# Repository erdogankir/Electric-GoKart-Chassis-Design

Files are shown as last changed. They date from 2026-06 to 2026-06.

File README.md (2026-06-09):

# Electric Go-Kart Chassis Design & Structural Optimization 🏎️⚡

This repository contains the conceptual design, mechanical engineering calculations, and Finite Element Analysis (FEA) of a handling-oriented electric go-kart chassis. 

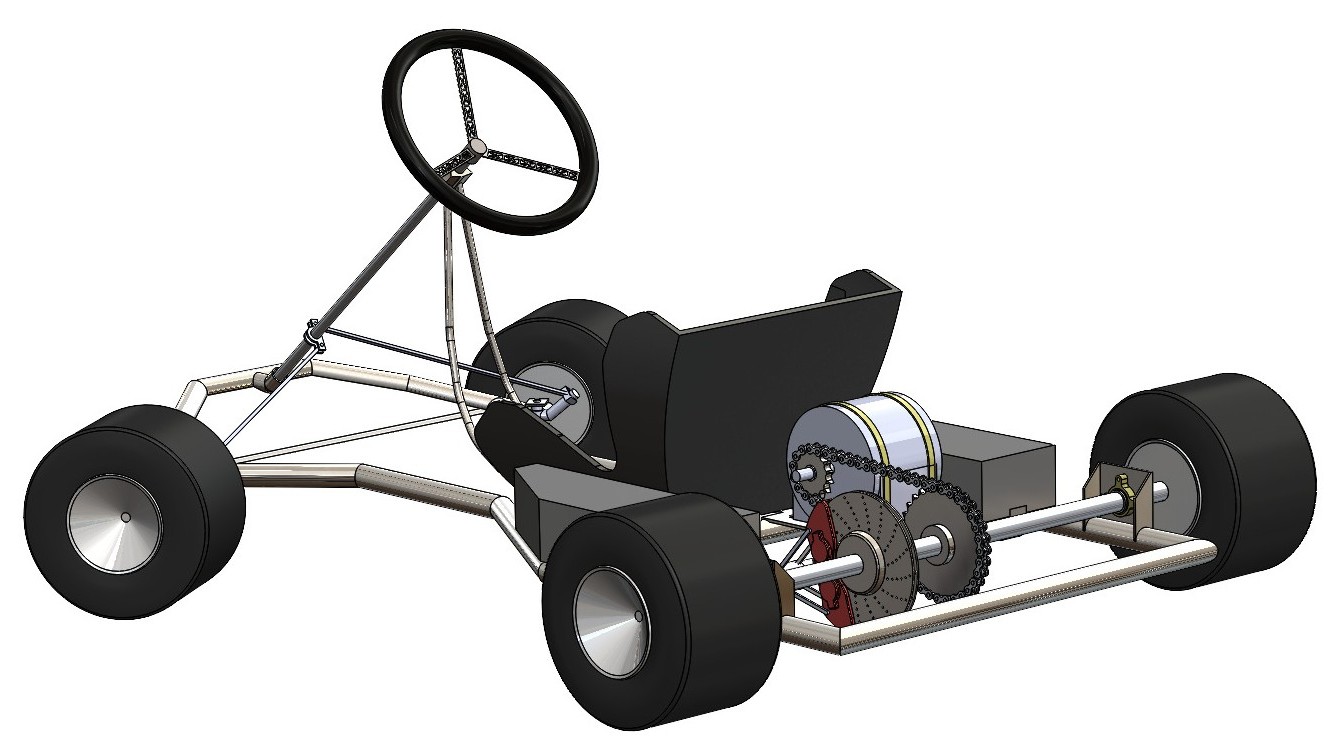
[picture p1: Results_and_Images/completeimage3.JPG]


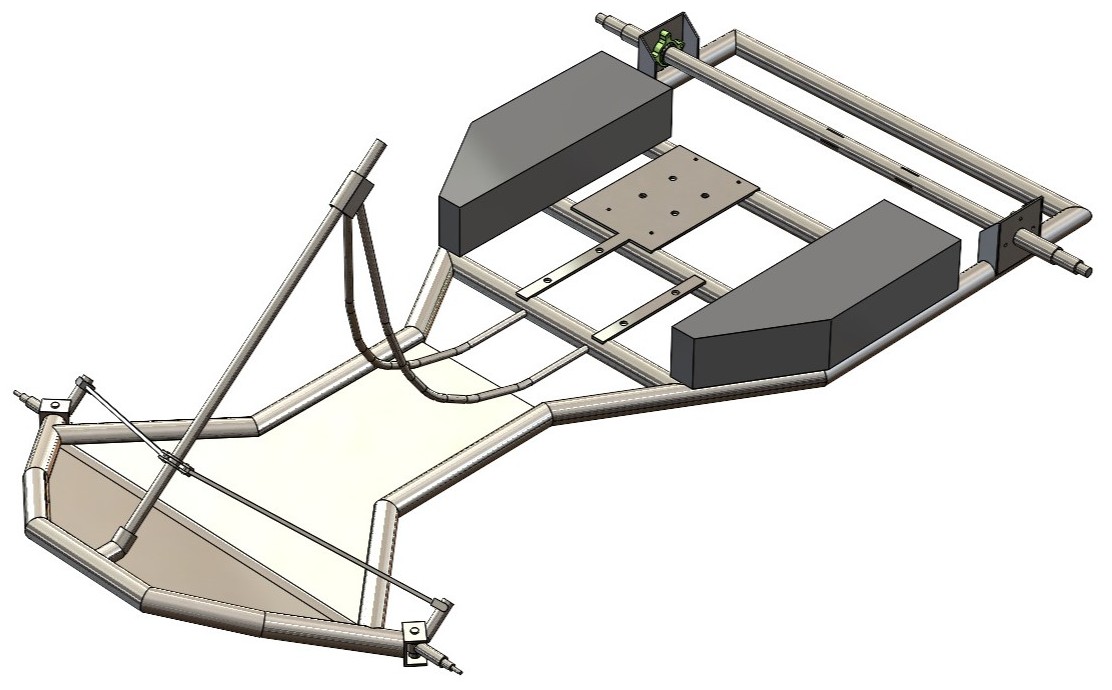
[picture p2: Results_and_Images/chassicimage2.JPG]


## 🎯 Project Overview
Unlike standard automobiles, go-karts lack a suspension system. This requires the chassis itself to act as the suspension. This project focuses on optimizing the torsional rigidity of the chassis to successfully achieve the **"jacking effect"** (lifting the inner rear wheel during cornering) to prevent understeer, effectively compensating for the added weight of an EV battery pack.

## ⚙️ Technical Specifications
* **Chassis Material:** S355 Structural Steel Tubing (32x2mm for main rails, 25x2mm for supports)
* **Powertrain:** 1.7 kW 48V Brushless DC (BLDC) Motor
* **Energy Storage:** 14S10P Li-Ion Battery Pack (18650 NMC cells, ~1.5 kWh) managed by a 60A BMS
* **Top Speed:** ~60 km/h (Optimized via 3.69 gear ratio)
* **Wheelbase / Track Width:** 1160 mm / 1400 mm

## 🔬 Engineering Methodology & Analysis
All design and simulation phases were executed using **SolidWorks 2024**. The engineering workflow includes:

1. **Vehicle Dynamics:** Quasi-Static Load Transfer calculations to determine cornering forces and theoretical load shifts.
2. **Global FEA (Beam Elements):** Initial displacement and rigidity tests under dynamic cornering loads (up to 550N lateral shock).
3. **Sub-Modeling (Solid Elements):** High-stress regions, particularly the steering knuckle connections (stub axles), were isolated and detailed using sub-modeling techniques. 
   * *Result:* Max Von Mises stress of **283 MPa** (Safely below the 355 MPa yield limit of S355 steel).
4. **Fatigue Analysis:** The 25mm rear axle was verified for infinite life under dynamic loads using the **Soderberg Criterion**.
5. **Stability:** Buckling analysis confirmed a critical load factor of 1.6.

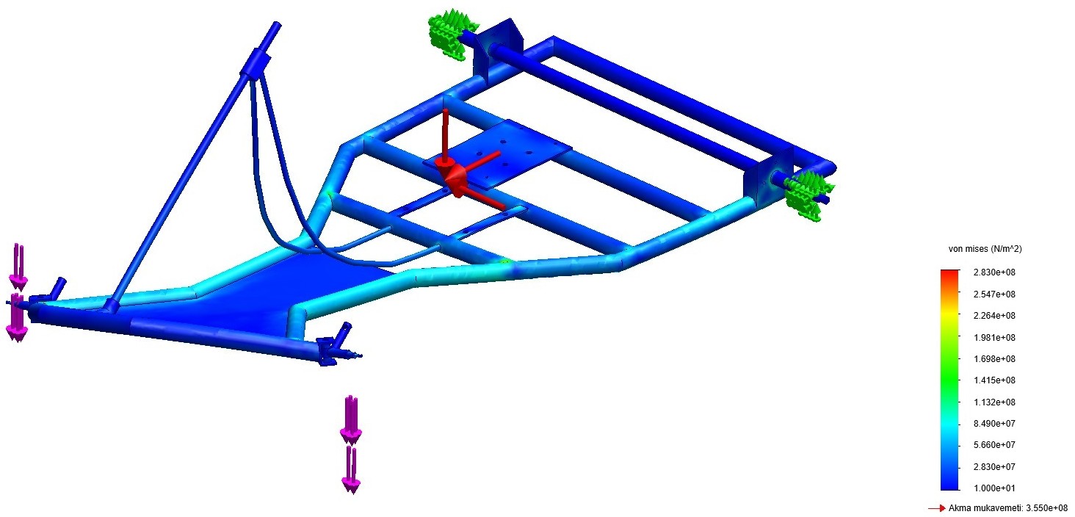
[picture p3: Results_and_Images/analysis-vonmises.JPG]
FEA Stress Distribution


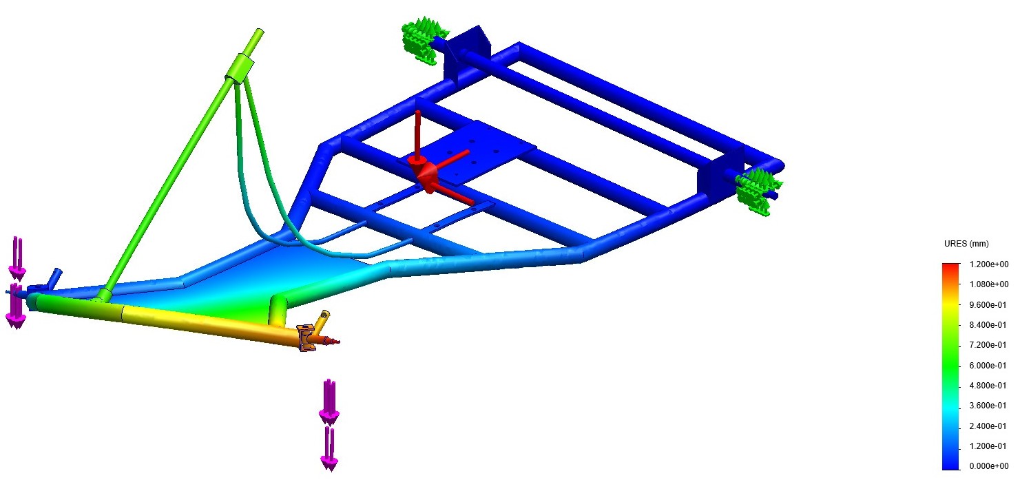
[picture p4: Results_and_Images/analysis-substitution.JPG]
FEA Substitution


## 📂 Repository Structure
* `/CAD_Models`: Contains SolidWorks native parts/assemblies (.sldprt, .sldasm) and exported .STEP files for universal access.
* `/Results_and_Images`: High-resolution CAD renders and FEA stress distribution contour plots.
* `/Documentations`: The comprehensive engineering design report (in Turkish) detailing all mathematical models, material selection, and cost analysis.

---
*Designed by Erdoğan Kır as a senior Mechatronics Engineering design project.*

NON-COMMERCIAL USE ONLY

---
# Elektrikli Go-Kart Şasi Tasarımı ve Yapısal Optimizasyonu 🏎️⚡

Bu depo, yol tutuş odaklı bir elektrikli go-kart şasisinin kavramsal tasarımını, makine mühendisliği hesaplamalarını ve Sonlu Elemanlar Analizi'ni (FEA) içermektedir.

Chassis Assembly

Chassis Assembly

## 🎯 Proje Özeti
Standart otomobillerden farklı olarak, go-kartlar bir süspansiyon sistemine sahip değildir. Bu durum, şasinin kendisinin bir süspansiyon elemanı gibi davranmasını zorunlu kılar. Bu proje, elektrikli araç batarya paketinin ek ağırlığını telafi ederek önden kaymayı (understeer) önlemek ve viraj dönüşlerinde iç arka tekerleği kaldırmak olan **"jacking effect"** (kaldırma etkisi) mekanizmasını başarıyla sağlamak için şasinin burulma rijitliğini optimize etmeye odaklanmaktadır.

## ⚙️ Teknik Özellikler
* Şasi Malzemesi:** S355 Yapı Çeliği Boru (Ana kollar için 32x2mm, destekler için 25x2mm) 
* **Güç Aktarma Sistemi:** 1.7 kW 48V Fırçasız DC (BLDC) Motor 
* Enerji Depolama:** 60A BMS ile yönetilen 14S10P Li-İyon Batarya Paketi (18650 NMC hücreler, ~1.5 kWh) 
* **Maksimum Hız:** ~60 km/s (3.69 dişli oranı ile optimize edilmiştir) 
* **Aks Aralığı / İz Genişliği:** 1160 mm / 1400 mm 

## 🔬 Mühendislik Metodolojisi ve Analiz
Tüm tasarım ve simülasyon aşamaları **SolidWorks 2024** kullanılarak gerçekleştirilmiştir. Mühendislik iş akışı şunları içerir:

1. **Araç Dinamiği:** Viraj kuvvetlerini ve teorik yük transferlerini belirlemek için Yarı-Statik Yük Transferi hesaplamaları.
2. **Global FEA (Kiriş Elemanlar):** Dinamik viraj yükleri altında (550N'a kadar yanal şok) ilk yer değiştirme ve rijitlik testleri.
3. **Alt Modelleme (Katı Elemanlar):** Özellikle direksiyon mafsal bağlantıları (stub axles) gibi yüksek gerilme bölgeleri izole edilmiş ve alt modelleme teknikleri kullanılarak detaylandırılmıştır.
   * *Sonuç:* Maksimum Von Mises gerilmesi **283 MPa** (S355 çeliğinin 355 MPa akma sınırının güvenli bir şekilde altındadır).
4. **Yorulma Analizi:** 25mm arka aks milinin dinamik yükler altındaki sonsuz ömrü **Soderberg Kriteri** kullanılarak doğrulanmıştır.
5. **Stabilite:** Burkulma analizi (buckling) 1.6'lık kritik yük faktörünü doğrulamıştır.

FEA Stress Distribution

FEA Substitution

## 📂 Depo Yapısı
* `/CAD_Models`: SolidWorks yerel parça/montaj dosyalarını (.sldprt, .sldasm) ve evrensel erişim için dışa aktarılmış .STEP dosyalarını içerir.
* `/Results_and_Images`: Yüksek çözünürlüklü CAD render'larını ve FEA gerilme dağılımı haritalarını içerir.
* `/Documentations`: Tüm matematiksel modelleri, malzeme seçimini ve maliyet analizini detaylandıran kapsamlı mühendislik tasarım raporu.

---
*Mekatronik Mühendisliği tasarım projesi olarak Erdoğan Kır tarafından tasarlanmıştır.* 

SADECE TİCARİ OLMAYAN KULLANIM İÇİNDİR

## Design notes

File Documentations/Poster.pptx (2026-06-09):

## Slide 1

YOL TUTUŞ ODAKLI ELEKTRİKLİ GO-KART
TASARIMI VE YAPISAL OPTİMİZASYONU
(Mekatronik Mühendisliği Tasarımı)

Erdoğan KIR Doç. Dr. Gökhan ATALI

32

Yapılan çalışma ve projede herhangi bir fon desteği alınmamıştır.

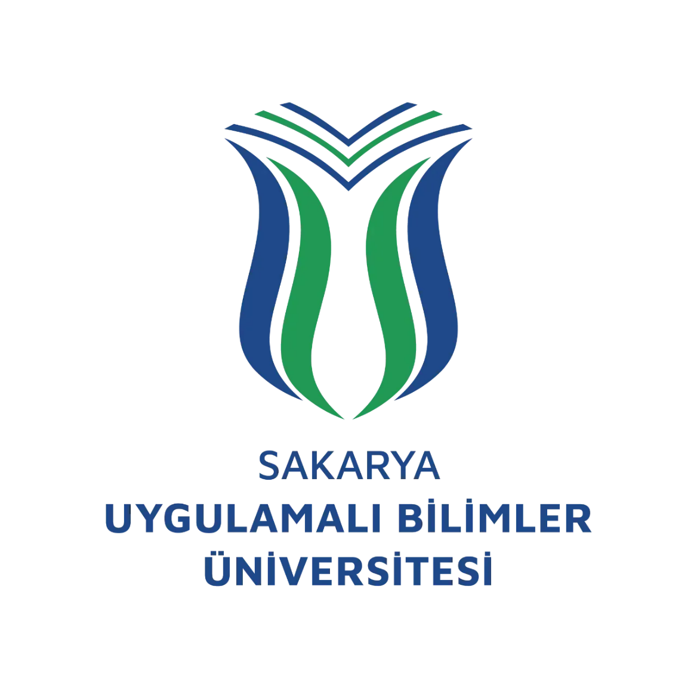
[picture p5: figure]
grafik, grafik tasarım, logo, simge, sembol içeren bir resim

MEKATRONİK
MÜHENDİSLİĞİ
PROJE SERGİSİ
2025-2026 Güz

3 2

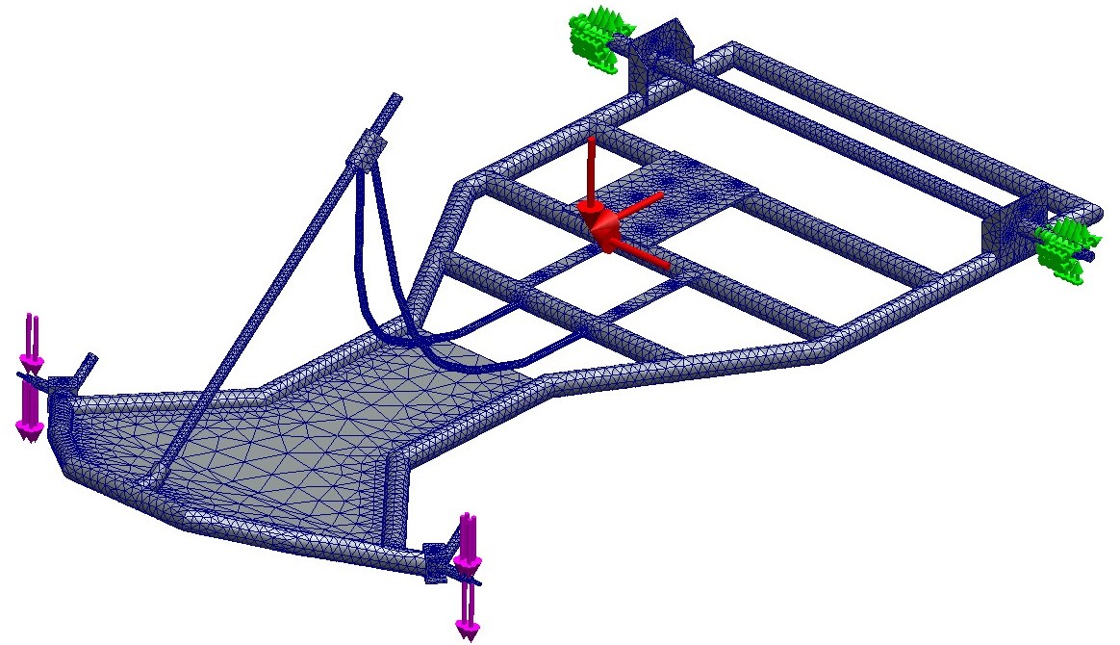
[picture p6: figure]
taslak, çizim, oyun alanı, çocuk bahçesi, çocukların yaptığı resimler içeren bir resim Yapay zeka tarafından oluşturulmuş içerik yanlış olabilir.

GİRİŞ

taslak, çizim, tasarım içeren bir resim Yapay zeka tarafından oluşturulmuş içerik yanlış olabilir.

SONUÇ & TARTIŞMA

32

Otomotiv endüstrisindeki radikal elektrifikasyon dönüşümü, motor sporlarının giriş seviyesi ve en saf hali olarak kabul edilen karting disiplinini de yeniden şekillendirmektedir. Özellikle kapalı alan (indoor) pistlerinde egzoz emisyonlarının yarattığı sağlık riskleri ve havalandırma maliyetleri, elektrikli tahrik sistemlerine olan talebi artırmıştır. Ayrıca, Fırçasız DC (BLDC) motorların içten yanmalı motorlara kıyasla sıfır devirden itibaren sunduğu maksimum tork avantajı, teorik olarak viraj çıkışlarında üstün bir ivmelenme performansı vadetmektedir. Ancak geleneksel go-kart araçlarının süspansiyonsuz yapısı, yol tutuş karakteristiğini doğrudan şasinin burulma rijitliğine (torsional rigidity) ve esnekliğine bağımlı kılmaktadır.
Bu çalışmadaki temel mühendislik problemi; elektrikli araç mimarisinin kaçınılmaz bir sonucu olan ağır batarya paketlerinin şasiye entegrasyonudur. Bu ek ağırlık, şasinin doğal frekansını ve esneklik merkezini değiştirerek, viraj performansı için hayati önem taşıyan "Jacking Effect" (viraj içi arka tekerleğin yerden kesilerek diferansiyel etkisi yaratılması) mekanizmasını bozma riski taşımaktadır. Şasinin gereğinden fazla rijit olması durumunda araç virajı dönemeyerek önden kayma (understeer) eğilimi gösterirken; aşırı esnek olması durumunda ise enerji sönümlenmesi nedeniyle direksiyon tepkileri gecikmektedir.
Bu bağlamda proje, literatürde kabul görmüş Gillespie (1992) araç dinamiği teorisi ve Mihalić ve ark. (2023) tarafından geliştirilen elektrikli şasi konsepti referans alınarak kurgulanmıştır. Çalışmanın nihai hedefi; S355 yapı çeliği ve yerel üretim imkanları (boru büküm, kaynaklı birleştirme) kullanılarak, batarya ağırlık dağılımının optimize edildiği, viraj içi frenleme ve dinamik yük senaryoları altında yapısal bütünlüğünü koruyan, maliyet etkin ve performanslı bir elektrikli go-kart platformu tasarlamaktır.

32

Yapısal Bütünlük ve Sonlu Elemanlar Analizi (FEA):
SolidWorks Simulation ortamında, viraj dışı tekerlek için belirlenen 550 N kritik tasarım yükü altında gerçekleştirilen statik analizlerde, şasi genelindeki maksimum yer değiştirme (deformasyon) şasi merkezinde yalnızca 1.2 mm olarak tespit edilmiştir. Bu düşük deformasyon değeri, şasinin "jacking effect" için gerekli rijitliğe sahip olduğunu kanıtlamaktadır. Von Mises gerilme analizi sonuçlarına göre; şasi üzerindeki maksimum gerilme, en zorlu yükleme senaryosunda dahi 283 MPa seviyesinde kalmıştır. Kullanılan S355 çeliğinin akma mukavemeti 355 MPa olduğu göz önüne alındığında, tasarımın plastik deformasyona uğramadan elastik sınırlar içerisinde güvenli bir şekilde çalıştığı doğrulanmıştır. Ayrıca, ince cidarlı borularda kritik bir risk olan burkulma (buckling) analizi sonucunda yük faktörü 1.6 olarak bulunmuş, bu da yapının mevcut yüklerin 1.6 katına kadar stabil kalabileceğini göstermiştir.

Kritik Bölge Doğrulaması ve Yorulma Ömrü:
Global analizde gerilme yığılmalarının yoğunlaştığı tespit edilen direksiyon mafsal bağlantıları (stub axle), "Alt Modelleme" (Sub-modeling) tekniği ile detaylandırılmıştır. Bu hassas analiz sonucunda, en kritik bölgedeki güvenlik katsayısının (FOS) 1.25 olduğu, şasi genelinde ise bu değerin 1.6 ile 4.0 arasında değiştiği görülmüştür . Yarış araçlarında ağırlık optimizasyonu için kabul edilebilir alt sınırın 1.25-1.5 olduğu düşünüldüğünde, tasarımın hem hafiflik hem de mukavemet açısından optimum noktada olduğu değerlendirilmiştir. Güç aktarım sisteminde ise, arka aks mili için uygulanan Soderberg Kriteri analizi, milin dinamik yükler altında sonsuz ömre sahip olacağını teorik olarak doğrulamıştır.

Maliyet Etkinliği ve Performans Kestirimi:
Tasarlanan elektrikli go-kart platformunun prototip üretim maliyeti, piyasa koşullarına göre (motor, batarya, şasi malzemeleri ve işçilik dahil) yaklaşık 97.420 TL olarak hesaplanmıştır. Bu maliyet, ithal edilen elektrikli yarış şasilerine kıyasla yerli üretimin ekonomik avantajını ortaya koymaktadır. Enerji yönetim simülasyonlarında, 1.7 kW motor ve 1512 Wh batarya paketi kombinasyonunun, aracı teorik olarak 60 km/s maksimum hıza ulaştırabileceği ve tam performanslı kullanımda 20 dakikalık yarış seansını termal limitlere takılmadan tamamlayabileceği öngörülmüştür.

taşımak, nakletmek, tekerlek, araba lastiği, Araba parçası içeren bir resim Yapay zeka tarafından oluşturulmuş içerik yanlış olabilir.

INTRODUCTIONasd

oyun alanı, çocuk bahçesi, ekran görüntüsü içeren bir resim Yapay zeka tarafından oluşturulmuş içerik yanlış olabilir.
oyun alanı, çocuk bahçesi, ekran görüntüsü, diyagram içeren bir resim Yapay zeka tarafından oluşturulmuş içerik yanlış olabilir.
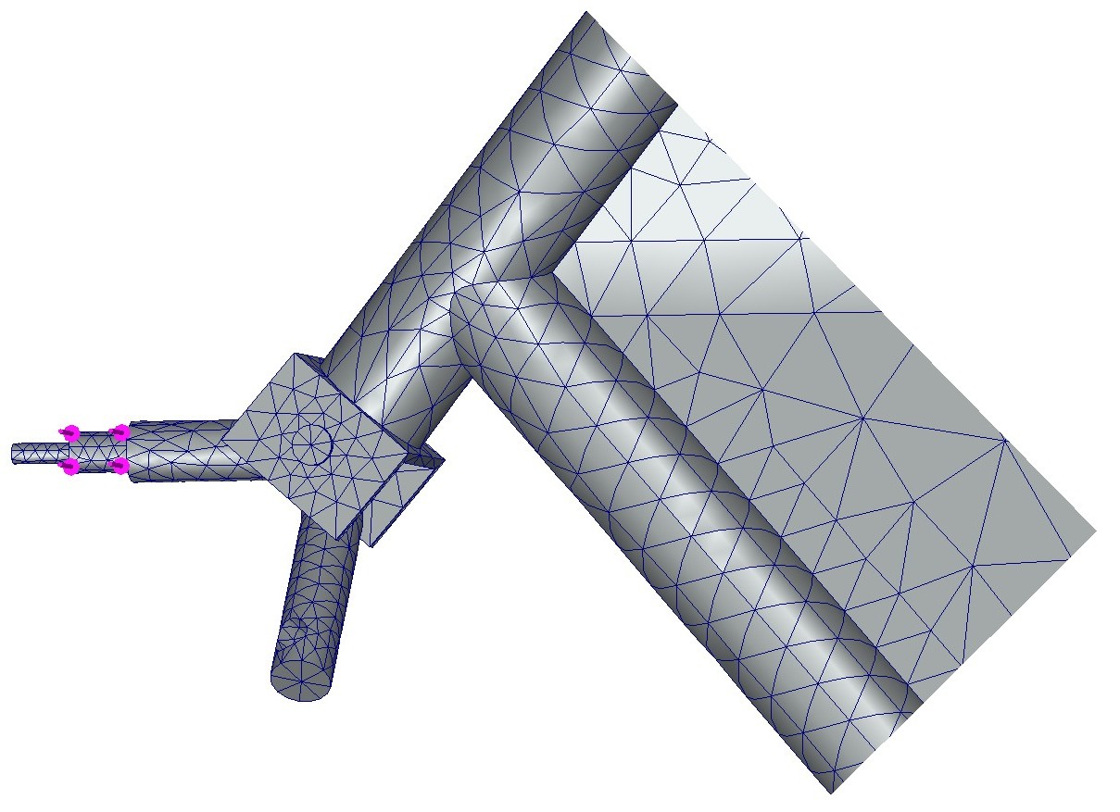
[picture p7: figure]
taslak, çizim içeren bir resim Yapay zeka tarafından oluşturulmuş içerik yanlış olabilir.
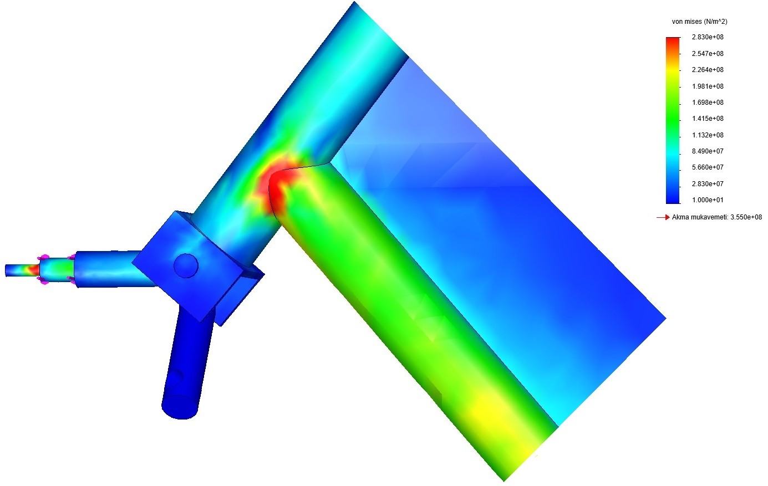
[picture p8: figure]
ekran görüntüsü, renklilik, grafik tasarım içeren bir resim Yapay zeka tarafından oluşturulmuş içerik yanlış olabilir.

32

Konsept Tasarım ve Malzeme Karakterizasyonu:
Bu çalışmada, sıfırdan şasi geometrisi oluşturmanın risklerini minimize etmek amacıyla literatür tabanlı "Tasarım Yoluyla Araştırma" (Research Through Design) metodolojisi benimsenmiştir. Şasi geometrisi, CIK-FIA tarafından belirlenen uluslararası standartlar (1040 mm aks aralığı ve 1400 mm iz genişliği) referans alınarak oluşturulmuş, ancak elektrikli tahrik sisteminin gereksinimleri doğrultusunda "side-pod" bölgeleri batarya taşıyıcı olarak yeniden yapılandırılmıştır. Malzeme seçiminde; havacılık çeliklerinin (AISI 4130) yüksek maliyeti ve düşük karbonlu çeliklerin (AISI 1020) yetersiz mukavemeti göz önüne alınarak optimizasyon yapılmış ve S355J2H dikişsiz çelik boru tercih edilmiştir . Seçilen malzemenin 355 MPa akma mukavemetine, 470-630 MPa çekme mukavemetine ve 7850 kg/m³ yoğunluğa sahip olması, şasi rijitliği ile ağırlık dengesinin korunmasını sağlamıştır . Şasi iskeletinde, yüksek burulma direnci gerektiren ana taşıyıcı hatlarda 32mm×2mm kesitli profiller kullanılırken; esneklik gerektiren ara bağlantı ve destek elemanlarında Ø25mm×2mm profiller kullanılarak ağırlık optimizasyonu sağlanmıştır.

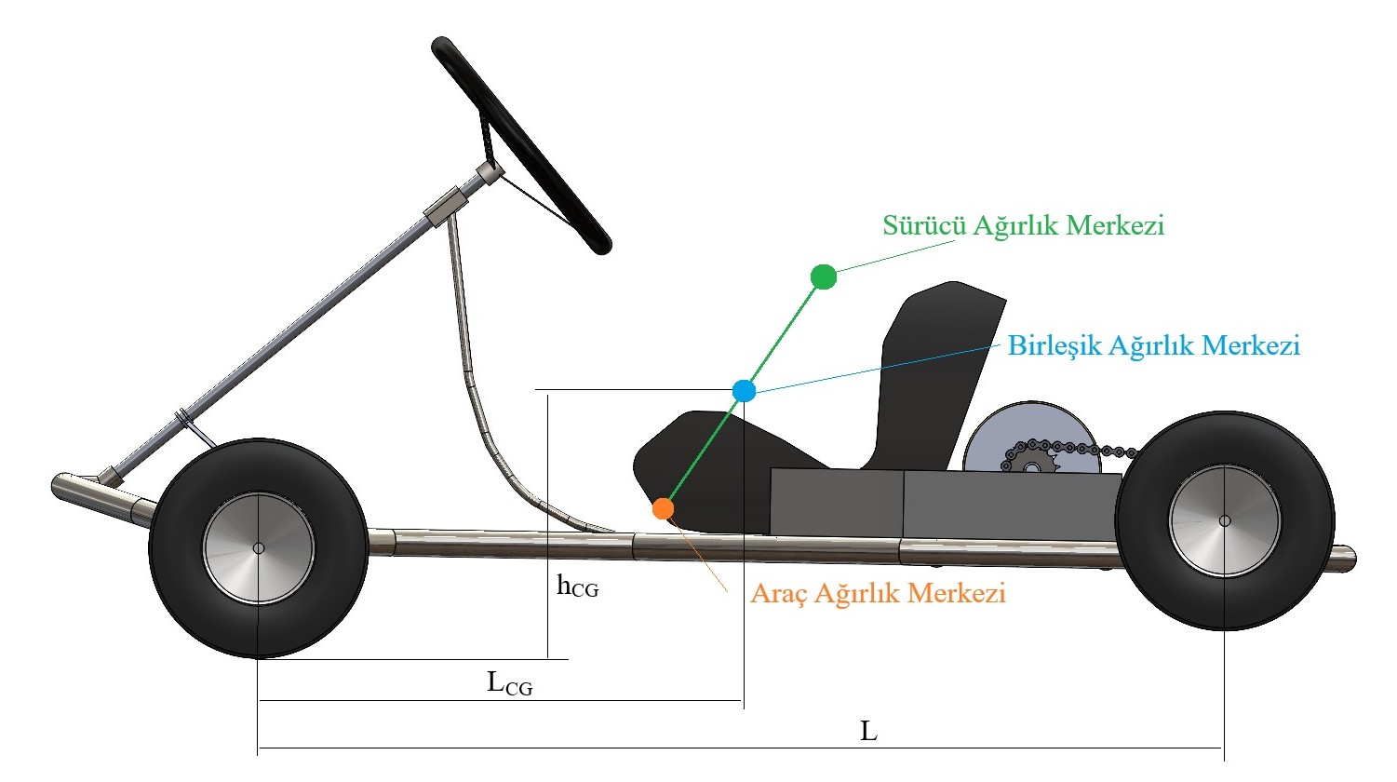
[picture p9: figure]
araba lastiği, tekerlek, Araba parçası, taşıt, araç içeren bir resim Yapay zeka tarafından oluşturulmuş içerik yanlış olabilir.

Yapısal Analiz (FEA) ve Güç Aktarım Entegrasyonu:
Aracın tahrik sistemi, toplam direnç kuvvetleri olan yuvarlanma ve aerodinamik dirençlerin (toplam 99.6 N) 16.6 m/s hızda yenilmesi prensibine göre boyutlandırılmıştır. Bu gereksinimi karşılamak üzere %90 sistem verimliliğine sahip 1.7 kW 48V Fırçasız DC (BLDC) motor sisteme entegre edilmiştir. Tork iletiminde zincir-dişli mekanizması kullanılmış; motor devri ve tekerlek devri oranlanarak 3.69:1 (13T Motor / 48T Aks) redüksiyon oranı belirlenmiştir. Enerji depolama ünitesi olarak, 20 dakikalık yarış süresi boyunca termal stabiliteyi koruyacak ve 1512 Wh enerji kapasitesi sunacak 14S10P konfigürasyonunda Li-Ion batarya paketi tasarlanmıştır. Batarya güvenliği, hücre voltajlarını 4.2V seviyesinde dengeleyen ve 60A üzeri akım çekiminde devreyi kesen Deligreen 14S BMS modülü ile sağlanmıştır. Ayrıca arka aks mili tasarımında Soderberg Yorulma Kriteri uygulanarak, dinamik eğilme ve burulma momentleri altında mil çapının 25 mm olması gerektiği doğrulanmıştır.

MATERYAL & YÖNTEM

Araç Dinamiği ve Yük Simülasyonu:
Aracın viraj alma performansı, Gillespie (1992) tarafından literatüre kazandırılan "Yarı-Statik Yük Transferi" (Quasi-Static Load Transfer) yaklaşımı ile modellenmiştir. Simülasyon senaryosu olarak; 16 metre viraj yarıçapında 10 m/s hızla seyreden ve 6.25 m/s² yanal ivmeye maruz kalan toplam 130 kg kütleli (sürücü dahil) bir araç modellenmiştir. Bu senaryoda ağırlık merkezi yüksekliğinin şasi stabilitesine etkisi analiz edilerek, viraj dışı tekerleklere etkiyen dinamik yükler teorik olarak hesaplanmıştır. Sonlu Elemanlar Analizi (FEA) süreçlerinde kullanılacak sınır şartları (boundary conditions) belirlenirken, sadece statik yükler değil, pist koşullarındaki olası darbeler de hesaba katılmıştır. Bu doğrultuda, viraj dışı arka tekerlek için teorik yükün üzerine dinamik şok faktörü eklenerek 550 N değerinde bir tasarım yükü tanımlanmış; viraj içi tekerlek yükü ise "jacking effect" kabiliyetini doğrulamak adına 100 N seviyesine düşürülmüştür. Analizlerde kaynaklı birleşimler "bonded" (yapışık) kabul edilmiş ve çözüm ağı (mesh) oluşturulurken kritik bölgelerde eleman boyutu 2 mm'ye kadar düşürülmüştür.

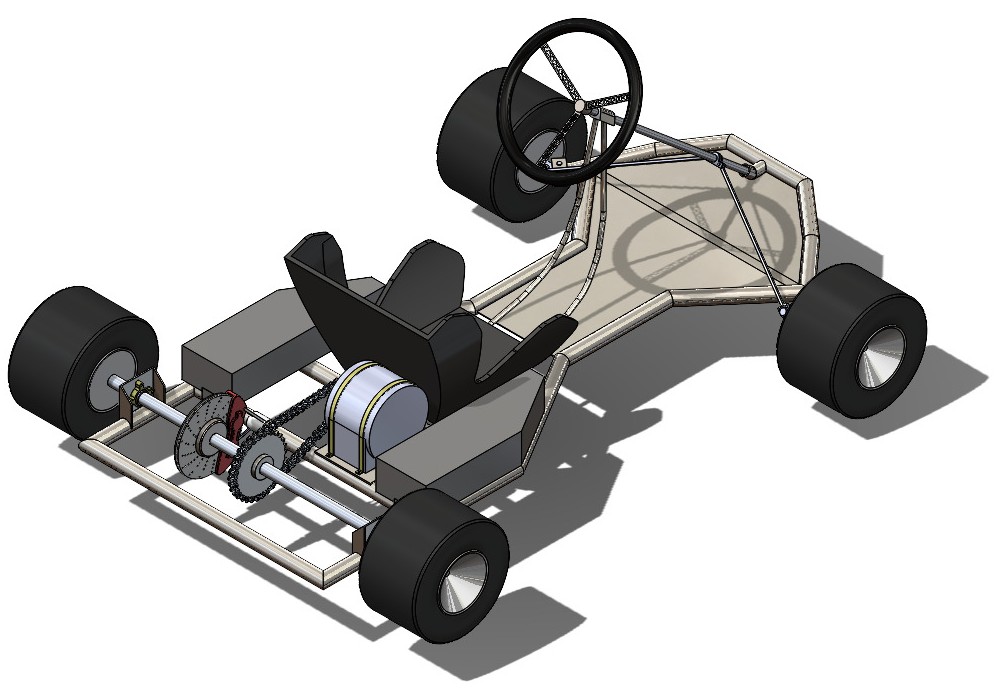
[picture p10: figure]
tekerlek, araba lastiği, taşımak, nakletmek, Araba parçası içeren bir resim Yapay zeka tarafından oluşturulmuş içerik yanlış olabilir.
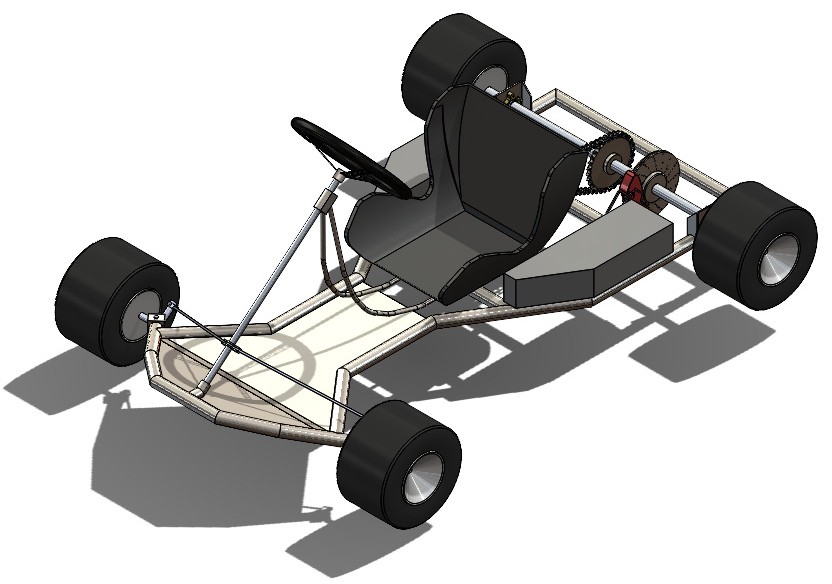
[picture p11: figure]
araba lastiği, tekerlek, taşımak, nakletmek, Araba parçası içeren bir resim Yapay zeka tarafından oluşturulmuş içerik yanlış olabilir.
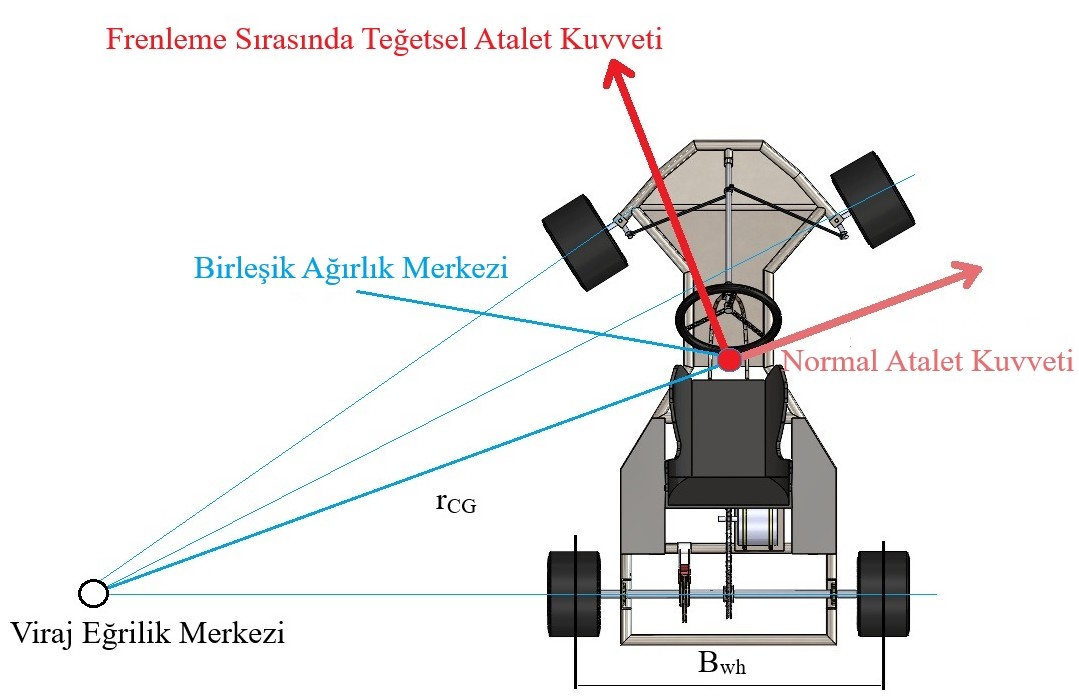
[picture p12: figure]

MATERIALS & METHODS

32

Bu proje, lisans seviyesinde bireysel bir tasarım çalışması olarak yürütüldüğünden, doğrulama süreçleri sanal prototipleme ve simülasyon ortamlarıyla sınırlı kalmıştır. Gelecek çalışmalarda, aracın fiziksel prototipinin üretilmesi ve şasi üzerine yerleştirilecek telemetri sensörleri (strain-gauge) ile esneklik davranışının gerçek pist koşullarında deneysel olarak doğrulanması önerilmektedir. Ayrıca, aracın güç/ağırlık oranını (power-to-weight ratio) daha da iyileştirmek adına; şasi malzemesi olarak mevcut S355 çeliği yerine daha hafif ve mukavemeti yüksek Krom-Molibden (AISI 4130) alaşımı kullanılabilir. Enerji depolama sisteminde ise, kullanılan 18650 Li-Ion hücreler yerine, gravimetrik enerji yoğunluğu daha yüksek olan Lityum-Polimer (Li-Po) batarya teknolojilerine geçiş yapılması, aracın dinamik performansını artıracaktır.

ÖNERİLER

32

Budynas, R.G. & Nisbett, K.J. (2011). Shigley's Mechanical Engineering Design. McGraw-Hill.
Gillespie, T.D. (1992). Fundamentals of Vehicle Dynamics. SAE International
Mihalić, T., Hoster, J., Tudić, V. & Kralj, T. (2023). 'Concept Design and Development of an Electric Go-Kart Chassis', Applied Sciences.
Milliken, W.F. & Milliken, D.L. (1995). Race Car Vehicle Dynamics. SAE International.

REFERANSLAR

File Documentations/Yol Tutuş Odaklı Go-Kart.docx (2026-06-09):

T.C.

SAKARYA UYGULAMALI BİLİMLER ÜNİVERSİTESİ
TEKNOLOJİ FAKÜLTESİ

MEKATRONİK MÜHENDİSLİĞİ BÖLÜMÜ

YOL TUTUŞ ODAKLI ELEKTRİKLİ GO-KART TASARIMI VE YAPISAL OPTİMİZASYONU

Mekatronik Mühendisliği Tasarımı Raporu

G180918066 Erdoğan KIR

Danışmanı | : | Doç. Dr. Gökhan ATALI

Ocak 2026

T.C.

SAKARYA UYGULAMALI BİLİMLER ÜNİVERSİTESİ
TEKNOLOJİ FAKÜLTESİ

MEKATRONİK MÜHENDİSLİĞİ BÖLÜMÜ

YOL TUTUŞ ODAKLI ELEKTRİKLİ GO-KART TASARIMI VE YAPISAL OPTİMİZASYONU

Mekatronik Mühendisliği Tasarımı Raporu

G180918066 Erdoğan KIR

Danışmanı | : | Doç. Dr. Gökhan ATALI

Danışman | Jüri | Jüri
Doç. Dr. Gökhan ATALI | Dr. Öğr. Üyesi Ayşe Nur AY GÜL | Arş. Gör. Nur Yasin PEKER

BEYAN

Rapor içindeki tüm verilerin akademik kurallar çerçevesinde tarafımdan elde edildiğini, görsel ve yazılı tüm bilgi ve sonuçların akademik ve etik kurallara uygun şekilde sunulduğunu, kullanılan verilerde herhangi bir tahrifat yapılmadığını, başkalarının eserlerinden yararlanılması durumunda bilimsel normlara uygun olarak atıfta bulunulduğunu, raporda yer alan verilerin bu üniversite veya başka bir üniversitede herhangi bir çalışmada kullanılmadığını beyan ederim.

Erdoğan KIR

05.12.2025

TEŞEKKÜR

Lisans eğitimim boyunca benden maddi ve manevi desteklerini esirgemeyen, her türlü zorlukta yanımda duran ve bu günlere gelmemde en büyük pay sahibi olan kıymetli aileme minnettarım.

Ayrıca, tasarım metodolojisi ve analiz akışının kurgulanmasında, 'Concept Design and Development of an Electric Go-Kart Chassis' başlıklı çalışmalarıyla yol gösterici olan Mihalić ve arkadaşlarına, akademik literatüre katkılarından dolayı teşekkürlerimi sunarım.

İÇİNDEKİLER

SİMGELER VE KISALTMALAR LİSTESİ

A | : Amper
A | : Araç ön projeksiyon alanı
Ah | : Ampere-Hour
AISI | : American Iron and Steel Institute
a_a^b | : Alternatif normal gerilme
a_m^b | : Ortalama normal gerilme
a_k^b | : Eğilme için gerilme katsayısı
a_(-1)^d | : Tersinir dinamik mukavemeti
a^y | : Yanal ivme
a^T | : Teğetsel ivme
a_k^t | : Burulma için gerilme katsayısı
BLDC | : Brushless Direct Current Motor
BMS | : Battery Management System
CAD | : Computer Aided Design
C_d | : Sürüklenme katsayısı
CIK | : Commission Internationale de Karting
CNC | : Computer Numerical Control
COG | : Center of Gravity
d | : Mil çapı
δ_0 | : Dış tekerlek açısı
δ_i | : İç tekerler açısı
ΔF_z | : Yük transferi
E | : Elastite modülü
EV | : Electric Vehicle
F_N^11 | : Ön sol lastik zemin reaksiyon kuvveti
F_N^12 | : Ön sağ lastik zemin reaksiyon kuvveti
F_N^21 | : Arka sol lastik zemin reaksiyon kuvveti
F_N^22 | : Arka sağ lastik zemin reaksiyon kuvveti
F_(aero) | : Aerodinamik direnç kuvveti
F_(dis) | : Yük transfer payı
F_(roll) | : Yuvarlanma direnci kuvveti
f_(roll) | : Yuvarlanma direnç katsayısı
F_(total) | : Toplam direnç kuvveti
FEA | : Finite Element Analysis
F_(in)^T | : Teğetsel atalet kuvveti
FIA | : Fédération Internationale de l’Automobile
FOS | : Factor of Safety
Φ | : Çap (Genel)
g | : Yerçekimi ivmesi
h_(CG) | : Ağırlık merkezi yüksekliği
i | : İdeal oran
kg (ağırlık) | : Kilogram
kW | : KiloWatt
L | : Aks aralığı
L_(CG) | : Ağırlık merkezinden ön aksa olan mesafe
LFP | : Lithium Iron Phosphate
LTO | : Lityum Titanat
M_b | : Eğilme momenti
M_T | : Tork
MPa | : Megapascal
m (uzunluk) | : Metre
mAh | : Miliampere Hour
mm (uzunluk) | : Milimetre
m/s | : Metre/Saniye
m/ s^2 | : Metre/Saniyekare
m_(com) | : Toplam kütle
m_d | : Sürücü kütlesi
m_i | : i 'inci bileşenin kütlesi
m_v | : Araç kütlesi
N | : Newton
n | : Güvenlik katsayısı
NMC | : Nikel Manganez Kobalt
ω | : İz genişliği
P | : Gerekli güç
P | : Paralel Bağlantı
PMSM | : Permanent Magnet Synchronous Motor
r_(CG) | : Viraj Yarıçapı
R_(eng) | : Motor Devri
R_(tire) | : Tekerlek Devri
r_a^t | : Alternatif kayma gerilmesi
r_m^t | : Ortalama kayma gerilmesi
ρ | : Yoğunluk
RPM | : Rotate Per Minute
S | : Seri Bağlantı
s | : Saniye
σ_a^(eku) | : Eşdeğer alternatif (yorulma) gerilmesi
σ_m^(eku) | : Eşdeğer ortalama gerilme
σ_(max) | : Maksimum gerilme
σ_(uts) | : Çekme momenti
σ_y | : Akma mukavemeti
T | : Dişli Diş Sayısı
TIG | : Tungsten Inert Gas
V | : Volt
V_(nom) | : Nominal gerilim
v | : Hız
W | : Watt
Wh | : Watt Hour
x_i | : Bileşenin referans nokta mesafesi

ŞEKİLLER LİSTESİ

TABLOLAR LİSTESİ

ÖZET

Anahtar Kelimeler: Elektrikli Go-Kart, Yol Tutuş Dinamiği, Şasi Tasarımı, Sonlu Elemanlar Analizi, Batarya Yönetim Sistemi, Araç Mühendisliği, Soderberg Kriteri.

Bu çalışma, Sakarya Uygulamalı Bilimler Üniversitesi Mekatronik Mühendisliği Tasarımı dersi kapsamında, içten yanmalı motorların çevresel dezavantajlarını elimine eden ve elektrik motorlarının tork avantajlarını kullanarak viraj alma kabiliyeti (yol tutuş) sergileyen bir elektrikli go-kart şasi ve güç aktarım sisteminin kavramsal tasarımını, mühendislik hesaplamalarını ve yapısal analizlerini içermektedir. Projenin temel motivasyonu, süspansiyon sistemine sahip olmayan go-kart araçlarında, şasi esnekliğinin ve rijitliğinin yol tutuş üzerindeki doğrudan etkisini optimize etmektir. Çalışma kapsamında, literatürde kabul görmüş tasarım ve analiz metodolojileri takip edilmiş; bu metodoloji, S355 çelik boru kullanılarak tarafımdan özgün olarak çizilen şasi geometrisi üzerinde uygulanmıştır

Tasarım sürecinde, aracın viraj içi frenleme, ani ivmelenme ve yol pürüzlerinden kaynaklanan darbe yükleri gibi kritik sürüş senaryoları modellenmiştir. Bu modellerden elde edilen viraj kuvvetleri, aracın yanal ivme altındaki davranışını simüle eden Yarı-Statik Yük Transferi (Quasi-Static Load Transfer) yöntemi ile hesaplanmış ve SolidWorks Simulation modülü kullanılarak Sonlu Elemanlar Analizi (FEA) ortamına aktarılmıştır. Şasinin gerilme dağılımı (Von Mises), yer değiştirme ve burkulma (buckling) davranışları incelenmiştir. Özellikle direksiyon mafsal bağlantıları (stub axle) gibi yüksek stres bölgeleri, alt modelleme (sub-modeling) tekniği ile detaylandırılarak, boru et kalınlığı/çap oranlarının güvenlik katsayıları üzerindeki etkisi irdelenmiştir. Arka aks mili tasarımı için Soderberg yorulma kriteri kullanılarak dinamik yükler altında mil ömrü doğrulanmıştır.

Analiz sonuçları, seçilen geometrinin 1.25 ile 2 arasında değişen güvenlik katsayıları ile elastik sınırlar içerisinde kaldığını ve yol tutuş için gerekli burulma esnekliğini sağladığını göstermiştir. Güç aktarma sisteminde, 1.7 kW güce sahip 48V Fırçasız DC (BLDC) motor ve 14S10P konfigürasyonunda Lityum-İyon batarya paketi kullanılmıştır. Batarya yönetim sistemi (BMS) entegrasyonu ve hücre dengeleme stratejileri, yarış koşullarında 20 dakika maksimum performans ve termal stabilite sağlayacak şekilde teorize edilmiştir. Araç dinamiği hesaplamalarında, ağırlık merkezi (COG) değişiminin lastik yük dağılımına etkisi ve diferansiyelsiz arka aksın viraj dönme mekaniği (jacking effect) üzerindeki rolü detaylıca analiz edilmiştir. Elde edilen bulgular, bu platformun hem yapısal bütünlük hem de dinamik performans açısından uygulanabilir, maliyet etkin ve performanslı bir çözüm sunduğunu ortaya koymaktadır.

ABSTRACT

Keywords: Electric Go-Kart, Handling Dynamics, Chassis Design, Finite Element Analysis, Battery Management System, Automotive Engineering, Soderberg Criterion.

This study presents the conceptual design, engineering calculations, and structural analyses of an electric go-kart chassis and powertrain system, developed within the scope of the Mechatronics Engineering Design course at Sakarya University of Applied Sciences. The study aims to eliminate the environmental disadvantages of internal combustion engines while utilizing the torque advantages of electric motors to exhibit superior cornering capability (handling). The project’s core motivation focuses on optimizing the direct impact of chassis flexibility and rigidity on handling in suspensionless go-kart vehicles. Within the scope of this study, design and analysis methodologies accepted in the literature were followed; this methodology was applied to a unique chassis geometry designed by the author using S355 steel tubing.

In the design process, critical driving scenarios such as braking during cornering, sudden acceleration, and impact loads resulting from road irregularities were modeled. Cornering forces obtained from these models were calculated using the Quasi-Static Load Transfer method to simulate the vehicle's behavior under lateral acceleration and were transferred to the Finite Element Analysis (FEA) environment using the SolidWorks Simulation module. The chassis was examined for Von Mises stress distribution, displacement, and buckling behaviors. High-stress regions, particularly the steering knuckle connections (stub axles), were detailed using the sub-modeling technique to investigate the effect of wall thickness-to-diameter ratios on safety factors. For the rear axle shaft design, the shaft life under dynamic loads was verified using the Soderberg fatigue criterion.

The analysis results demonstrated that the selected geometry remains within elastic limits with safety factors ranging between 1.25 and 2, providing the necessary torsional flexibility for optimal handling. The powertrain system utilizes a 1.7 kW 48V Brushless DC (BLDC) motor and a Lithium-Ion battery pack in a 14S10P configuration. Battery Management System (BMS) integration and cell balancing strategies were theorized to ensure thermal stability and maximum performance for 20 minutes under racing conditions. In vehicle dynamics calculations, the effect of Center of Gravity (COG) shifts on tire load distribution and the role of the differential-less rear axle on cornering mechanics (jacking effect) were analyzed in detail. The findings reveal that this platform offers a feasible, cost-effective, and high-performance solution in terms of both structural integrity and dynamic performance.

BÖLÜM 1. GİRİŞ

1.1. Çalışmanın Arka Planı ve Otomotiv Endüstrisindeki Dönüşüm

Otomotiv endüstrisi, son yüzyılın en köklü dönüşümlerinden birini yaşamakta ve fosil yakıtlı içten yanmalı motorlardan , sürdürülebilir ve yüksek verimli elektrikli tahrik sistemlerine (EV) geçiş yapmaktadır (Ehsani, Gao ve Emadi, 2010). Bu dönüşüm, yalnızca günlük ulaşım araçlarını değil, motor sporlarını da derinden etkilemektedir. Motor sporlarının giriş seviyesi ve en saf hali olarak kabul edilen "Karting", sürücülerin araç dinamiğini, yol tutuş limitlerini ve yarış çizgisi disiplinini öğrendikleri temel branştır. Geleneksel go-kartlar, basit mekanik yapıları, düşük ağırlık merkezleri ve süspansiyonsuz tasarımları ile bilinirler.

Özellikle kapalı alan (indoor) karting pistlerinde, egzoz gazlarının yarattığı havalandırma maliyetleri ve sağlık riskleri, elektrikli go-kartlara olan talebi artırmıştır. Elektrik motorlarının sıfır devirden itibaren maksimum tork üretebilme yeteneği, viraj çıkışlarında içten yanmalı motorlara kıyasla teorik olarak daha üstün bir ivmelenme performansı sunmaktadır. Ancak, elektrikli araçların en büyük handikabı olan batarya ağırlığı, hafiflik üzerine kurulu olan go-kart felsefesi ile çelişmektedir. Bu noktada, mühendislik disiplini devreye girmekte ve ağırlık dezavantajını, optimize edilmiş şasi geometrisi ve ağırlık dağılımı ile telafi ederek yol tutuş karakteristiğini koruma zorunluluğu doğmaktadır.

Bu proje akademik bir çerçevede endüstriyel standartlara yakın bir elektrikli go-kart platformu geliştirmek amacıyla kurgulanmıştır. Projenin arkasındaki temel motivasyon, yalnızca bir araç tasarlamak değil, aynı zamanda şasi esnekliğinin araç dinamiği üzerindeki etkisini matematiksel ve simülasyon tabanlı yöntemlerle kanıtlayarak başarılı ve teknik açıdan dolu bir mühendislik raporu ortaya koymaktır. Bu bağlamda, proje, literatürdeki başarılı tasarımların derinlemesine analizi ve bu tasarımların yerel imkanlar dahilinde optimize edilerek yeniden yorumlanması üzerine inşa edilmiştir.

1.2. Problem Tanımı: Yol Tutuş ve Elektrikli Tahrik Entegrasyonu

Go-kartlar, otomobillerden farklı olarak süspansiyon sistemine (yay, amortisör) sahip değildir. Bu durum, şasinin kendisinin bir süspansiyon elemanı gibi davranmasını zorunlu kılar. Aracın yol tutuşu, şasinin burulma rijitliği (torsional rigidity) ve esneklik karakteristiği ile doğrudan ilişkilidir. Viraj alma sırasında, şasi belirli bir miktarda esneyerek, diferansiyel bulunmayan arka aksın viraj içindeki tekerleğini yerden kesmeli veya yükünü minimize etmelidir. Buna jacking effect (kaldırma etkisi) denir. Eğer şasi çok rijit olursa, iç tekerlek kalkmaz ve araç virajı dönemeyerek önden kayar (understeer). Eğer şasi çok esnek olursa, enerji sönümlenir ve direksiyon tepkisi gecikir.

Elektrikli bir go-kartta, ağır batarya paketlerinin şasiye eklenmesi, şasinin doğal frekansını ve esneklik merkezini değiştirir. İçten yanmalı motorlu bir araca göre tasarlanmış standart bir şasiye elektrik motoru ve batarya takıldığında, aracın yol tutuş karakteristiği bozulur. Problem şudur: Ek batarya ağırlığına rağmen, virajlarda nötr veya hafif arkadan kayma (oversteer) eğilimli, yüksek yol tutuşa sahip ve mekanik olarak güvenli bir şasi geometrisi nasıl elde edilir?

1.3. Amaç ve Hedefler

Bu çalışmanın ana amacı, yol tutuş odaklı, elektrik tahrikli ve tek kişilik bir go-kart şasisi ve güç aktarım sistemi tasarlamaktır. Alt hedefler şunlardır:

1. Platform Seçimi ve Geliştirme: Sıfırdan şasi geometrisi yaratmanın getirdiği zaman ve bilgi birikimi kısıtlarını aşmak için, literatürde başarısı kanıtlanmış bir şasi geometrisinin referans alınarak, elektrikli bileşenlere uygun hale getirilmesi.
2. Mühendislik Hesaplamaları: Araç dinamiği, viraj kuvvetleri, ağırlık transferi, motor gücü ve batarya kapasitesi gibi parametrelerin teorik formüllerle hesaplanması.
3. Yapısal Analiz (FEA): Şasinin statik ve dinamik yükler (viraj, fren, darbe) altındaki davranışının SolidWorks Simulation ile analiz edilmesi ve güvenlik katsayılarının doğrulanması.
4. Enerji Yönetimi: Yarış koşulları için gerekli batarya kapasitesini ve BMS mimarisini belirlemek.

1.4. Projenin Kapsamı ve Sınırlılıkları

Bu rapor, aracın kavramsal tasarımını, detaylı mekanik analizlerini ve bileşen seçimlerini kapsamaktadır. Çalışma, fiziksel prototip üretiminden önceki nihai tasarım raporu niteliğindedir. Analizlerde şasi malzemesi olarak S355 çeliği kullanılmış, kaynaklı birleşimlerin ideal olduğu varsayılmıştır. Aerodinamik etkiler, aracın maksimum hızının (60 km/s) düşük olması nedeniyle basitleştirilmiş formüllerle hesaba katılmıştır.

BÖLÜM 2. LİTERATÜR ARAŞTIRMASI VE TEORİK ALTYAPI

2.1. Karting Disiplininin Mekanik Evrimi

Karting, 1956 yılında Art Ingels'in ilk aracı üretmesinden bu yana, basit mekanik yapılardan yüksek mühendislik ürünü araçlara evrilmiştir. Modern şasiler, CIK-FIA standartlarına göre krom-molibden veya karbon çeliklerinden üretilir. Şasinin esnekliği, lastiklerin yerle temasını optimize etmek için ayarlanabilir bir parametre olarak kullanılır. Elektrikli kartingde ise bu parametrelere batarya yerleşimi ve motor tork eğrisi yönetimi eklenmiştir.

2.2. Elektrikli Tahrik Sistemleri Literatürü

2.2.1. Fırçasız Doğru Akım (BLDC) Motor Karakteristikleri

Literatürde go-kart uygulamaları için en verimli motor tipinin BLDC veya PMSM olduğu belirtilmektedir. BLDC motorlar, fırçalı motorlara göre daha yüksek verim, daha yüksek güç yoğunluğu ve bakım gerektirmemesi nedeniyle tercih edilir. En kritik özelliği, geniş bir devir aralığında sabit tork sunabilmesidir, bu da vites kutusu ihtiyacını ortadan kaldırır.

2.2.2. Enerji Depolama: Li-Ion Hücre Kimyası ve Yönetimi

Enerji yoğunluğu (Wh/kg) açısından Lityum-İyon piller endüstri standardıdır (Miao ve ark., 2019). Go-kart tasarımında pil tercihi için üç ana başlık öne çıkar:

1. LFP ( LiFePO_4 ): Güvenli, uzun ömürlü (>2000 döngü), düşük enerji yoğunluğuna sahiptir.
2. NMC: Yüksek enerji yoğunluğuna sahiptir, otomotivde yaygındır.
3. LTO: Çok hızlı şarj edilebilme kapasitesi vw bunun getirisi olarak yüksek maliyetlidir.

Bu projede, performans/ağırlık gerekçesiyle NMC kimyasına sahip 18650 silindirik hücreler üzerine yoğunlaşılmıştır.

2.3. Araç Dinamiği Teorisi

2.3.1. Lastik-Yol Etkileşimi ve Sürtünme Çemberi

Bir aracın tüm kontrolü, lastiklerin yerle temas ettiği contact patch alanında gerçekleşir. Gillespie (1992) tarafından tanımlanan sürtünme çemberi teorisine göre, bir lastiğin üretebileceği maksimum yanal ve boylamasına kuvvetlerin bileşkesi, lastiğin sürtünme limitini aşamaz. Go-kartlarda süspansiyon olmadığı için, yük transferi doğrudan şasi esnekliği üzerinden lastiklere iletilir.

2.3.2. Ackermann Direksiyon Geometrisi ve Viraj Kinematiği

Düşük hızlarda tekerleklerin kaymadan dönmesi için Ackermann şartı (Denklem 3.1) sağlanmalıdır (Jazar, 2014).

cot(δ_0 )-cot(δ_i )=ω/L (3.1)

Burada δ_0 dış, δ_0 iç tekerlek açısı, ω iz genişliği ve L aks aralığıdır. Go-kartlarda bu geometri, viraj girişinde direksiyon çevrildiğinde ön tekerleklerin yükseklik farkı yaratarak şasiyi kurtarması ve iç arka tekerleği kaldırması için modifiye edilir.

2.3.3. Jacking Etkisi ve Yük Transferi Mekaniği

Diferansiyelsiz arka aks, virajda her iki tekerleği aynı hızda dönmeye zorlar. Dış tekerlek daha uzun yol alması gerektiğinden, iç tekerlek kaymak (scrubbing) zorundadır. Bu, aracı düz gitmeye zorlar (understeer). "Jacking" etkisi, şasinin esneyerek viraj içindeki arka tekerleğin üzerindeki yükü sıfıra indirmesi (veya havaya kaldırması) prensibidir. Bu sayede araç üç tekerlek üzerinde dönerek diferansiyel etkisi yaratır. Yük transferi ( ΔF_z ) şu şekilde (Denklem 3.2) ifade edilir:

ΔF_z =(m.a_y .h_(CG))/ω (3.2)

Ağırlık merkezi yüksekliğinin ( h_(CG) ) optimize edilmesi bu nedenle kritiktir.

2.4. Şasi Malzemeleri ve Metalurjik İnceleme

Şasi malzemesi seçiminde mukavemet, tokluk, kaynaklanabilirlik ve maliyet dengesi gözetilir. Literatürdeki çalışmalar incelendiğinde üç ana malzeme grubu öne çıkmaktadır:

- Krom-Molibden Çeliği (AISI 4130): Havacılık ve profesyonel yarış şasilerinde standarttır. Yüksek akma mukavemeti (460 MPa) ve mükemmel yorulma direnci sunar. Ancak kaynak sonrası ısıl işlem gerektirmesi ve yüksek maliyeti, öğrenci projeleri için erişilebilirliğini kısıtlar.
- Düşük Karbonlu Çelikler (AISI 1018 / 1020): Kolay işlenir, ucuzdur ancak mukavemeti düşüktür (300 MPa), bu da şasinin ağırlaşmasına neden olur.
- Yapı Çeliği (S355 / St52): Bu çalışmada tercih edilen malzemedir. Akma mukavemeti ( σ_y =355 MPa) ile AISI 4130'a yaklaşırken, maliyet ve kaynaklanabilirlik açısından karbon çeliklerinin avantajlarını sunar. Tokluğu yüksektir, darbe anında gevrek kırılma yerine plastik deformasyon gösterir.

BÖLÜM 3. MATERYAL VE YÖNTEM

3.1. Konsept Tasarım Yaklaşımı ve Geometri Seçimi

Sıfırdan şasi geometrisi yaratmanın riskleri göz önüne alınarak, Tasarım Yoluyla Araştırma (Research Through Design) metodolojisi izlenmiştir. CIK-FIA onaylı şasilerin geometrik parametreleri aks aralığı 1040mm ve iz genişliği 1400mm referans alınmış, bu geometri elektrik motoru ve batarya paketlerinin yerleşimine uygun olarak modifiye edilmiştir. Özellikle side pod bölgeleri batarya taşıyıcı olarak yeniden tasarlanmıştır.

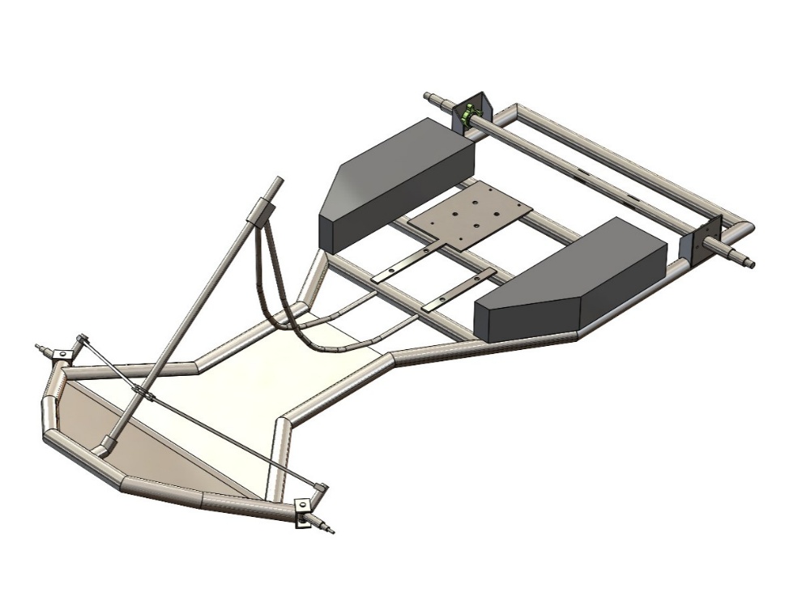
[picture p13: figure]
taslak, çizim, sandalye, tasarım içeren bir resim Yapay zeka tarafından oluşturulmuş içerik yanlış olabilir.

Şekil 3.1. SolidWorks ortamında tasarlanan şasi geometrisinin ön mafsallar, direksiyon mili ve batarya kutusu yerleşiminin izometrik görünümü.

3.2. Malzeme Seçimi ve Özelllikleri

Şasi ana taşıyıcı boruları için S355J2H dikişsiz çelik boru seçilmiştir. Malzeme özellikleri:

- Akma Mukavemeti ( σ_y ): 355 MPa
- Çekme Mukavemeti ( σ_(uts) ): 470-630 MPa
- Elastisite Modülü ( E ): 210 GPa
- Yoğunluk ( ρ ): 7850 kg/m³

Kullanılan boru kesitleri:

- Ana Şasi Kolları: Φ 32mm x 2mm (Dış Çap x Et Kalınlığı) Yüksek rijitlik gerektiren bölgeler.
- Ara Bağlantılar ve Destekler: Φ 25mm x 2mm Esneklik ve hafiflik gerektiren bölgeler.

3.3. Bilgisayar Destekli Tasarım (CAD) Süreci

Şasinin 3 boyutlu modellemesi SolidWorks 2024 yazılımında gerçekleştirilmiştir (Dassault Systèmes, 2023). Modelleme sürecinde Katı Modülleme (Solid Modelling) modülü kullanılarak, boru profillerin birleşim noktaları otomatik olarak düzenlenmiş ve kesim listeleri hazır hale getirilmiştir. Batarya kutuları, motor ve direksiyon bileşenleri ise montaj (assembly) ortamında şasiye entegre edilerek hacim ve ağırlık kontrolleri yapılmıştır.

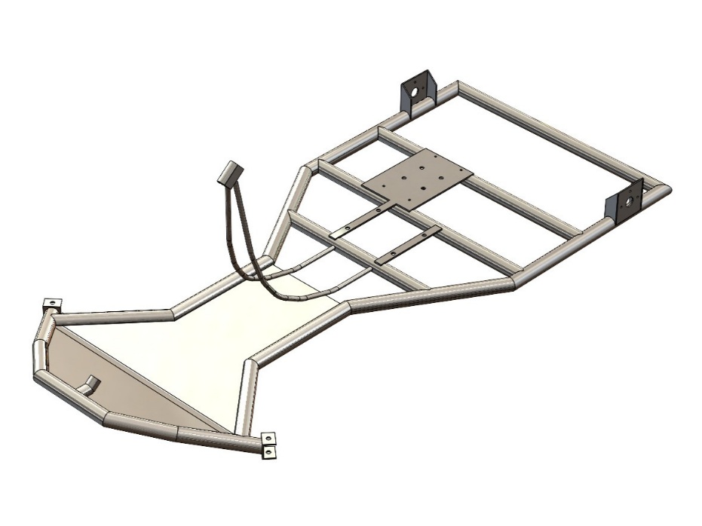
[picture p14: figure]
taslak, çizim, tasarım içeren bir resim Yapay zeka tarafından oluşturulmuş içerik yanlış olabilir.

Şekil 3.2. Katı modelleme modülü ile oluşturulan şasi iskelet yapısının ve bağlantı noktalarının genel görünümü.

3.4. Sonlu Elemanlar Analizi (FEA) Metodolojisi

Yapısal analizler, SolidWorks Simulation eklentisi ile yapılmıştır. Analiz adımları:

1. Ön İşlem (Pre-processing): Malzeme ataması ve bağlantı koşullarının belirlenmesi. Kaynaklı birleşimler bonded (yapışık) olarak kabul edilmiştir.
2. Mesh (Ağ) Oluşturma: İki aşamalı bir yaklaşım izlenmiştir.

Kiriş (Beam) Mesh: Tüm şasi, hesaplama hızı için kiriş elemanlarla modellenmiştir. Bu, şasinin genel deplasmanını görmek için idealdir. Katı (Solid) Mesh: Kritik gerilme bölgeleri (direksiyon mafsalları) katı elemanlarla modellenmiş, eleman boyutu 2 mm'ye kadar düşürülmüştür.

3. Çözüm (Solution): Statik analiz ve burkulma (buckling) analizi çözücüleri kullanılmıştır.
4. Son İşlem (Post-processing): Von Mises gerilme dağılımları, güvenlik katsayısı (FOS) grafikleri ve deformasyonlar görselleştirilmiştir.

BÖLÜM 4. MÜHENDİSLİK HESAPLAMALARI

4.1. Sürücü ve Araç Kütle Merkezi (COG) Analizi

Yol tutuşun kutsal kasesi ağırlık merkezidir. Aracın toplam kütlesi ( m_v ) 50 kg (bataryalar dahil), sürücü kütlesi ( m_d ) 80 kg olarak alınmıştır. Toplam kütle ( m_(com) ) 130 kg'dir.

SolidWorks kütle özellikleri aracından alınan veriler ve teorik formüllerle (Denklem 4.1) hesaplanan değerler:

L_(CG) =(m_i x_i)/(m_i) (4.1)

- Ağırlık Merkezi Yüksekliği ( h_(CG) ): 0,35 m
- Ön Aksa Mesafe ( L_(CG) ): 0,65 m
- Aks Aralığı ( L ): 1,16 m

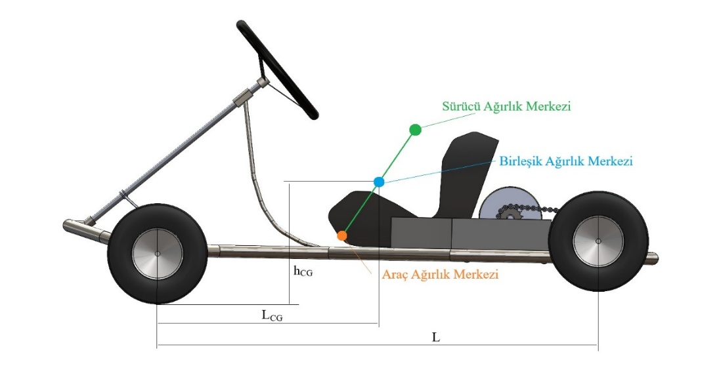
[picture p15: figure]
araba lastiği, tekerlek, Araba parçası, taşımak, nakletmek içeren bir resim Yapay zeka tarafından oluşturulmuş içerik yanlış olabilir.

Şekil 4.1. Sürücü ve araç bileşenlerinin ağırlık merkezlerinin (COG) dikey konumu ve aks mesafelerinin şematik gösterimi.

4.2. Yarı-Statik Yük Transferi Analizi (Quasi-Static Load Transfer)

4.2.1. Teorik Yük Transferi Hesabı

Aracın viraj alma performansı ve şasi üzerine binen yükler, Gillespie (1992) tarafından tanımlanan Yarı-Statik Yük Transferi yaklaşımı ile analiz edilmiştir. Varsayılan Senaryo:

- Viraj Yarıçapı ( r_(CG) ): 16 m
- Araç Hızı ( v ): 10 m/s
- Toplam Kütle ( m_(com) ): 130 kg
- Ağırlık Merkezi Yüksekliği ( h_(CG) ): 0.35 m
- İz Genişliği ( ω ): 1.4 m

İlk olarak araca etkileyen yanal ivme ( a_y ) ve merkezkaç kuvvetleri hesaplanmıştır (Denklem 4.2):

a_y =(v^2)/(r_(CG))=6,25 m/s^2 (4.2)

Toplam yanal yük transferi ( ΔF_z ), ağırlık merkezi yüksekliği ve iz genişliği oranına bağlı olarak şu şekilde bulunur (Denklem 4.3):

ΔF_z =(m_(com) .a^y .h_(CG))/ω=203,1 N (4.3)

Aracın 4 tekeri olduğu ve ağırlığın eşit dağıldığını varsaydığımız (basit yaklaşım) için (Denklem 4.4):

(1275,3)/4=318,8 N (4.4)

Yük transferi payı (Denklem 4.5):

(203,1)/2=101,55

F_(dis) =318+101,5=419,5 N (4.5)

Bu hesaba göre, viraj dışındaki tekerleğe binen teorik yük yaklaşık 420 N (318 + 101.5) seviyesindedir. Ancak statik hesaplamalar, yarış sırasındaki dinamik şokları kapsamamaktadır.

4.2.2. FEA Analizleri İçin Tasarım Yüklerinin (Boundary Conditions) Belirlenmesi

Şasinin sınırlarını test etmek amacıyla, teorik hesaplamaların üzerine Dinamik Yük Faktörü eklenerek analiz yükleri artırılmıştır. Tablo 4.1'de, Sonlu Elemanlar Analizi'nde (FEA) kullanılan ve güvenlik katsayısını içeren nihai yükler sunulmuştur.

Tablo 4.1. Teorik hesaplama ve analiz için oluşturulan kuvvetler ve açıklamaları

Konum | Sembol | Teorik Hesap | Analiz Yükü | Açıklama
Arka Sol (İç) | F_N^11 | ~216 N | 100 N | Viraj içinde fren yapıldığı varsayılarak yükün öne transfer olduğu ve iç tekerleğin yerden kesilme noktasına yaklaştığı an simüle edilmiştir.
Arka Sağ (Dış) | F_N^12 | ~420 N | 550 N | Teorik yüke yaklaşık 1.3 kat şok yükü eklenerek şasi mukavemeti garanti altına alınmıştır.
Ön Sol (İç) | F_N^21 | ~216 N | 270 N | Ön tekerleklerdeki yük, direksiyon açısı ve caster etkisiyle dengelendiği için teorik sınırlarda tutulmuştur.
Ön Sağ (Dış) | F_N^22 | ~420 N | 380 N | Direksiyon ve viraj yükü.

Yukarıdaki tabloda görüldüğü üzere, arka dış tekerlek için 550 N yükü baz alınmıştır. Bu değer, aracın sadece viraj dönmesini değil, viraj dönerken bir tümseğe girmesi veya bordüre çıkması durumunda şasinin burulmadan dayanabileceğini kanıtlamak için seçilmiştir. Benzer şekilde, iç tekerlek yükünün 100 N seviyesine düşürülmesi, şasinin "jacking" (iç tekerleği kaldırma) kabiliyetini doğrulamak içindir.

4.3. Güç Aktarma Sistemi Hesaplamaları

4.3.1. Direnç Kuvvetleri ve Güç Gereksinimi

Toplam direnç kuvveti ( F_(total) ), yuvarlanma ( F_(roll) ) ve aerodinamik ( F_(aero) ) dirençlerin (Denklem 4.6, Denklem 4.7) toplamıdır.

F_(roll) =m_(com) ⋅g⋅f_(roll) =130⋅9,81⋅0,025=31,9 N (4.6)

F_(aero) =1/2ρAC_d v^2 =0,5⋅1,23⋅0,5⋅0,8⋅(16,6)^2 =67,7 N (4.7)

Gerekli Güç (Denklem 4.8):

P=(F_(roll) +F_(aero) )⋅v=(31,9+67,7)⋅16,6≈1653 W (4.8)

Sistem verimi ( η =0.9) ile 1.7 kW motor seçimi doğrulanmıştır.

4.3.2. Dişli Oranı Optimizasyonu

Hesaplamalar sonucu gerekli dişli oranları ve hesaplamaları şu şekildedir:

- Motor Devri: 4600 RPM
- Tekerlek Devri (60 km/s): 1245 RPM
- İdeal Oran (Denklem 4.9) ( i ): 4600/1245 ≈ 3,7

i=(R_(eng))/(R_(tire)) (4.9)

- Seçilen Dişliler: Motor 13T, Aks 48T, Oran=3,69

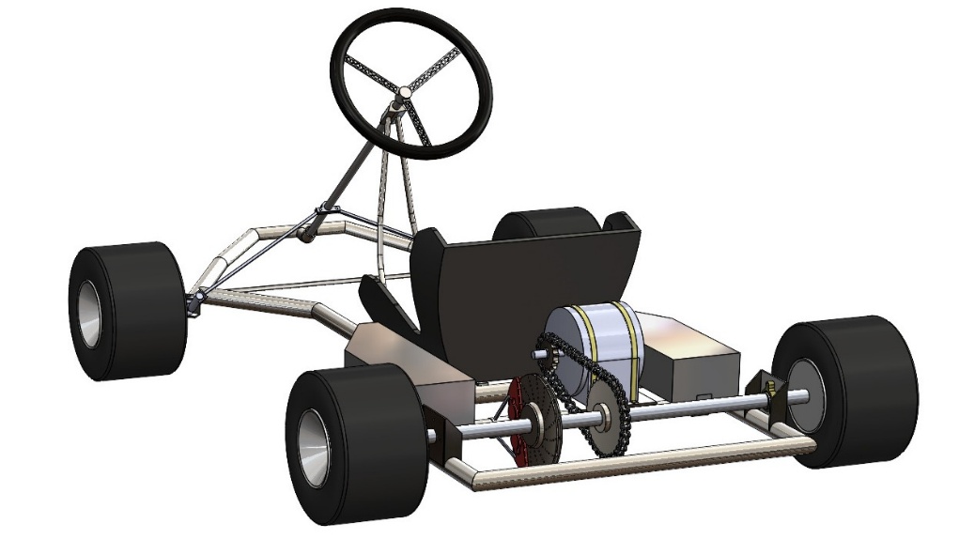
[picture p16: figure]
taşımak, nakletmek, tekerlek, araba lastiği, Araba parçası içeren bir resim Yapay zeka tarafından oluşturulmuş içerik yanlış olabilir.

Şekil 4.2. BLDC motor, zincir-dişli mekanizması ve arka aks grubunu içeren güç aktarım sisteminin montaj görünümü.

4.4. Arka Aks Mili Dinamik Mukavemet ve Yorulma Analizi

Arka aks, burulma ve viraj kuvvetleri altında karmaşık gerilmelere maruz kalır. Milin ömür hesabı için Soderberg Kriteri kullanılmıştır (Budynas & Nisbett, 2011).

4.4.1. Soderberg Kriteri ile Mil Çapı Tayini

Eşdeğer Gerilmeler (Denklem 4.9, Denklem 4,10) (Von Mises):

σ_a^(ekv) =√((α_k^b σ_a^b )^2 +3(α_k^t τ_a^t )^2) (4.10)

σ_m^(ekv) =√((α_k^b σ_m^b )^2 +3(α_k^t τ_m^t )^2) (4.11)

Soderberg Denklemi (Denklem 4,12):

(σ_a^(ekv))/(σ_(-1)^d)+(σ_m^(ekv))/(σ_y)=1/n (4.12)

σ_(-1)^d : Tersinir dinamik mukavemeti (285 MPa)

4.4.2. Kritik Kesitlerde Gerilme Yığılmaları

Hesaplanan momentler:

Eğilme Momenti ( M_b ): 52 Nm (En kötü senaryo)

Tork ( M_t ): 10.7 Nm

Gerekli mil çapı hesaplaması (Denklem 4.13):

d=√(16n.π) (4.13)

Sonuç olarak, kama kanalı ve rulman yataklarında minimum çap 19.3 mm olarak bulunmuş, güvenlik payı ile 25 mm aks kullanımına karar verilmiştir.

4.5. Batarya Paketi Enerji Kapasitesi ve Konfigürasyon Tasarımı

Yarış süresi (20 dk) ve motor gücü (1.7 kW) baz alınarak (Denklem 4.14):

E_(req) =P⋅t=1700⋅(20/60)=567 Wh (4,14)

Güvenlik faktörü ile hedef 1000 Wh olarak belirlenmiştir.

- Hücre Seçimi: 18650 Li-Ion (3.6V, 3000 mAh).
- Konfigürasyon: 14 Seri (14S) × 10 Paralel (10P).
- Nominal Voltaj: 14 × 3.6 = 50.4 V
- Kapasite: 10 × 3Ah = 30Ah
- Toplam Enerji (Denklem 4.15):

△E_(req) =V_(nom) ×Ah=50,4×30=1512Wh (4.15)

Hedefin üzerindedir ve uzun ömür sağlar.

BÖLÜM 5. YAPISAL ANALİZ VE TASARIM DOĞRULAMA (FEA)

Bu bölümde mühendislik hesaplamalarıyla belirlenen yüklerin şasi üzerindeki etkileri SolidWorks Simulation kullanılarak analiz edilmiştir.

5.1. Kiriş (Beam) Eleman Analizi ve Global Davranış

İlk aşamada, şasi boruları Kiriş (Beam) elemanlarla modellenmiştir. Bu yöntem, hesaplama süresini kısaltır ve şasinin genel esneme davranışını gösterir.

- Malzeme: S355 Çelik
- Yükleme: Tablo 4.1' deki 550 N (arka tekerlek) ve 270 N (ön tekerlek) yükleri uygulanmıştır.
- Sonuç: Maksimum deformasyon şasi merkezinde 1.2 mm olarak tespit edilmiştir. Bu, şasinin rijitliğinin yeterli olduğunu gösterir.

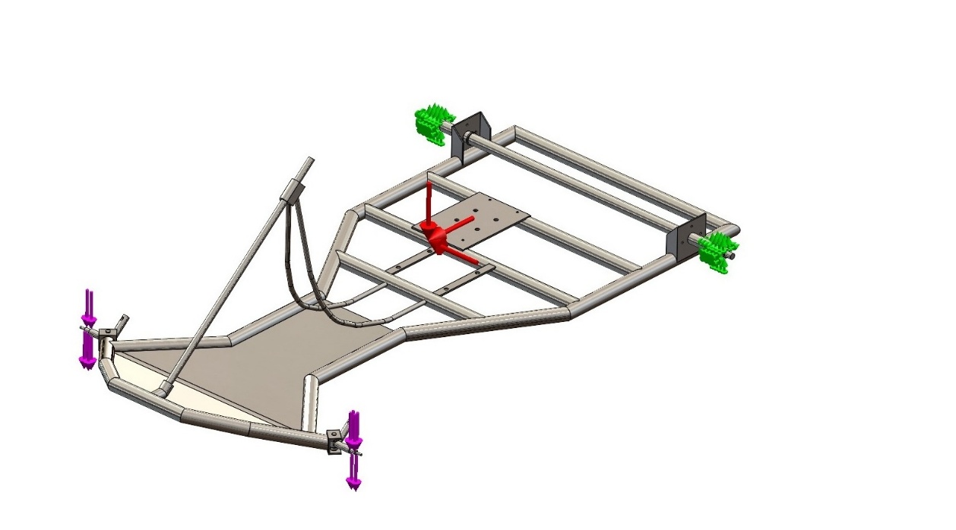
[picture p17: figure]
taslak, çizim, tasarım içeren bir resim Yapay zeka tarafından oluşturulmuş içerik yanlış olabilir.

Şekil 5.1. Yapısal analiz için şasiye tanımlanan sınır şartları ve tekerlek reaksiyon kuvvetlerinin uygulanması.

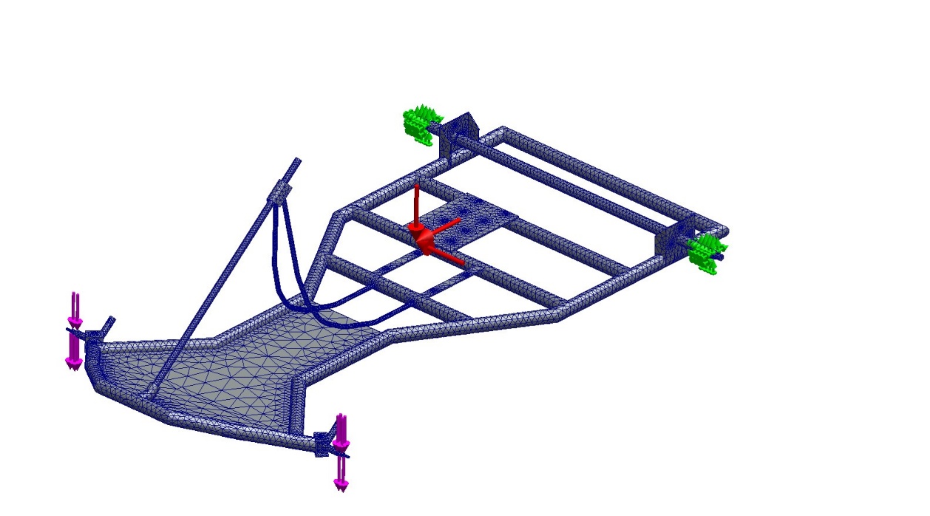
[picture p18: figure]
çizim, taslak, çocukların yaptığı resimler, oyun alanı, çocuk bahçesi içeren bir resim Yapay zeka tarafından oluşturulmuş içerik yanlış olabilir.

Şekil 5.2. Analiz sürecinde hesaplama amacıyla şasi üzerinde oluşturulan mesh yapısı.

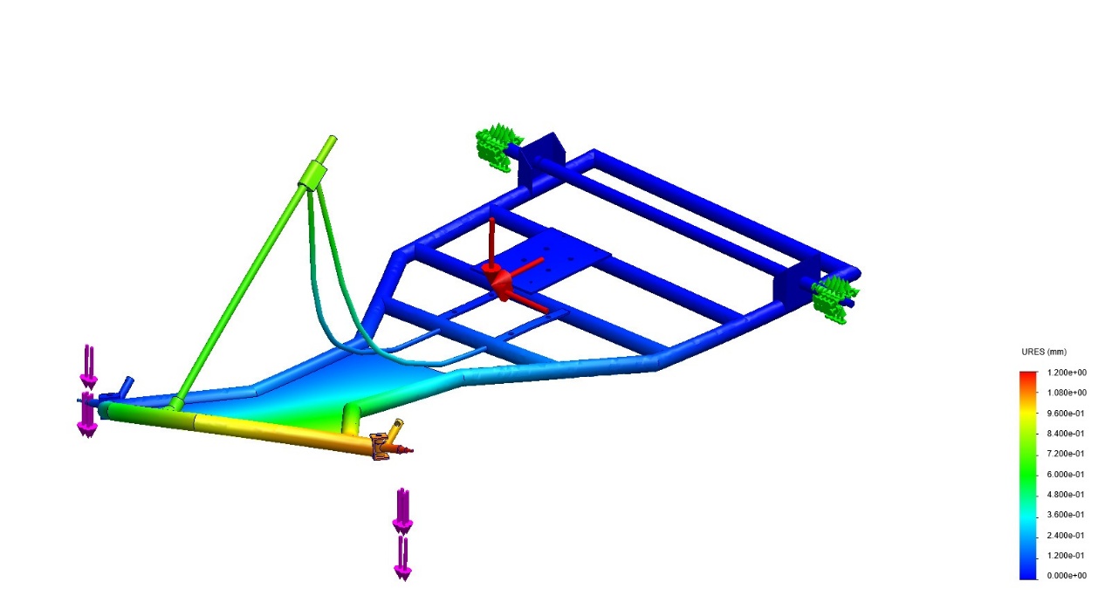
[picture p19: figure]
oyun alanı, çocuk bahçesi, ekran görüntüsü içeren bir resim Yapay zeka tarafından oluşturulmuş içerik yanlış olabilir.

Şekil 5.3. Statik yükleme senaryosu altında şasi gövdesinde meydana gelen toplam yer değiştirme (deformasyon) analizi sonucu.

5.2. Kritik Bölgelerin Tespiti ve Alt Modelleme (Sub-Modeling)

Global analizde tespit edilen kritik bölgelerin daha hassas incelenmesi amacıyla, referans çalışmada (Mihalić ve ark., 2023) önerilen ve güvenilir sonuçlar verdiği belirtilen 'Alt Modelleme (Sub-Modeling)' tekniği bu çalışmaya adapte edilmiştir. Bu sayede, kiriş elemanların yetersiz kaldığı mafsal bağlantılarındaki gerilme yığılmaları, literatürdeki yaklaşıma sadık kalınarak katı (solid) elemanlarla doğrulanmıştır.

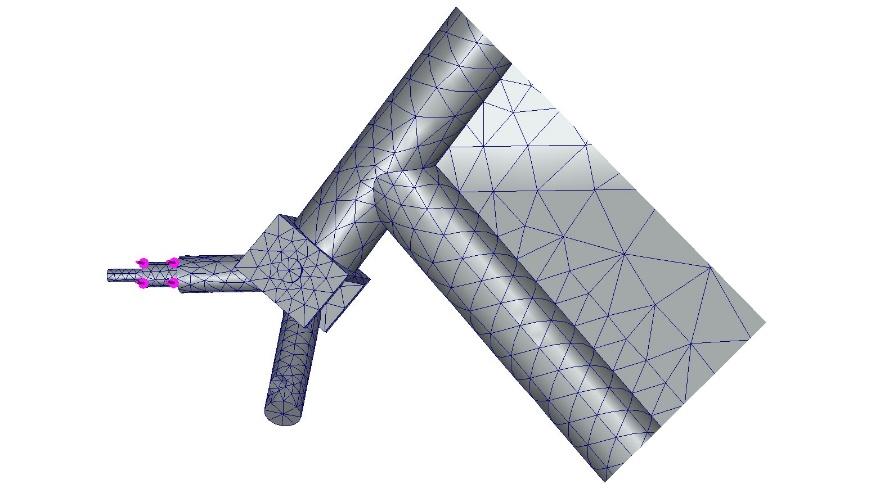
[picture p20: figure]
taslak, çizim, sanat içeren bir resim Yapay zeka tarafından oluşturulmuş içerik yanlış olabilir.

Şekil 5.4. Kritik gerilme bölgesi olan ön mafsal (stub axle) için oluşturulan katı (solid) alt model ve mesh ağı.

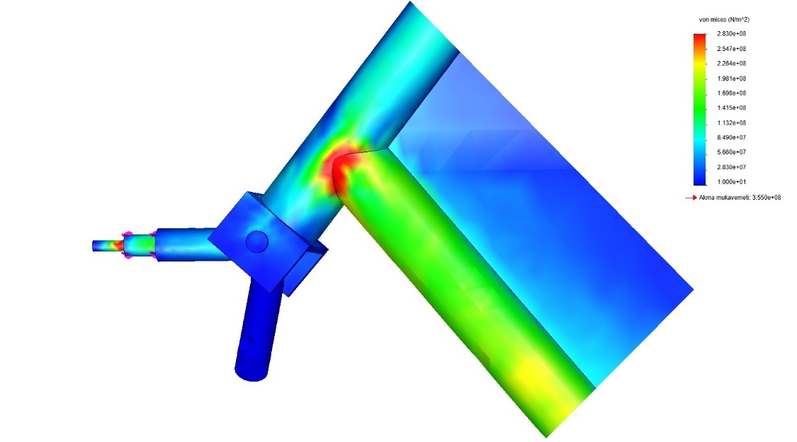
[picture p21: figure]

Şekil 5.5. Alt modelleme tekniği ile detaylandırılan direksiyon mafsal bağlantısındaki Von Mises gerilme dağılımı.

5.3. Dinamik Viraj Yükleri Altında Von Mises Gerilme Analizi

Alt modelleme sonucunda elde edilen Von Mises gerilme dağılımı incelendiğinde:

- Maksimum Gerilme: 283 MPa (Kaynak dikiş bölgelerinde).
- Malzeme Akma Sınırı: 355 MPa.
- Sonuç: Gerilme, akma sınırının altındadır.

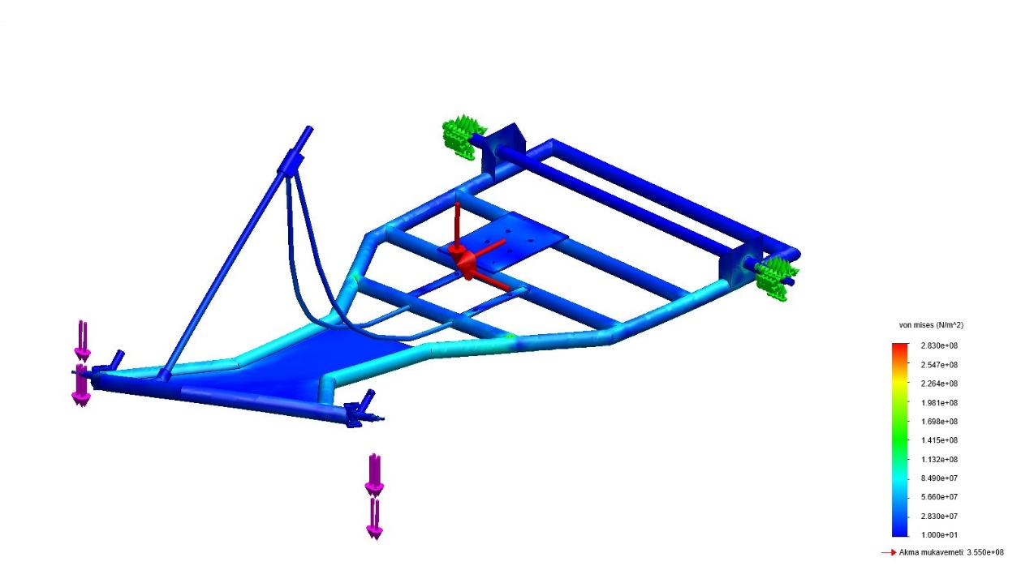
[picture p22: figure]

Şekil 5.6. Kritik viraj yükleri altında şasi genelindeki eşdeğer Von Mises gerilme dağılımının analizi.

5.4. Burkulma (Buckling) ve Stabilite Analizi

İnce cidarlı borularda (25mm çap, 2mm et kalınlığı) en büyük risk burkulmadır. SolidWorks Buckling modülü ile yapılan analizde:

- Kritik Yük Faktörü (Load Factor): 1.6
- Yorum: Bu değer, şasinin mevcut yüklerin 1.6 katına kadar burkulmadan dayanabileceğini gösterir. Dinamik yükler için 1.5 ve üzeri güvenli kabul edilir.

5.5. Güvenlik Katsayısı (FOS) Değerlendirmesi

En kritik bölgedeki güvenlik katsayısı (Denklem 5.1):

FOS=(σ_y)/(σ_(max))=355/283≈1.25 (5.1)

Şasinin genelinde ise FOS değerleri 2.0 ile 4.0 arasındadır. Yarış araçlarında ağırlık tasarrufu için 1.25-1.5 arası FOS değerleri kabul edilebilir sınırlardadır.

BÖLÜM 6. ELEKTRİK VE KONTROL SİSTEMLERİ TASARIMI

6.1. Batarya Yönetim Sistemi (BMS) Entegrasyonu

Lityum pillerin güvenliği için Deligreen 14S 60A BMS modülü seçilmiştir. Bu sistemin görevleri:

- Aşırı Akım Koruması: Motor kalkışında 60A üzeri akım çekilirse devreyi keser.
- Hücre Dengeleme: Şarj sırasında tüm hücre voltajlarını 4.2V seviyesinde eşitler (Pasif Dengeleme).
- Sıcaklık İzleme: Batarya sıcaklığı 60°C'yi geçerse sistemi kapatır.

6.2. Hücre Yerleşimi ve Termal Yönetim Stratejileri

140 adet 18650 hücresi, sürücünün sağında ve solunda bulunan side pod boşluklarına iki ayrı paket (7S10P + 7S10P) olarak yerleştirilmiştir. Bu yerleşim:

- Ağırlık merkezini aşağı çeker ( h_(CG) optimizasyonu).
- Sağ-sol ağırlık dengesini sağlar.
- Hava akışı ile pasif soğutmaya imkan tanır.

BÖLÜM 7. MALİYET ANALİZİ VE ÜRETİLEBİLİRLİK

7.1. Malzeme ve Bileşen Maliyet Dökümü

Prototip üretimi için öngörülen maliyetler (Aralık 2025 fiyatları):

Tablo 7.1. Maliyet Analizi

Malzeme/Bileşen | Özellik | Miktar | Birim Fiyat | Toplam (TL)
S355 Çelik Boru | Φ32mm × 2mm | 12 metre | 400 | 4,800
S355 Çelik Boru | Φ25mm × 2mm | 6 metre | 320 | 1,920
BLDC Motor Kiti | 48V 1,7kW + Sürücü | 1 set | 26.000 | 26.000
Li-ion Piller | 18650 (3000mAh) | 140 adet | 180 | 25,200
BMS Modülü | 14S 60A | 2 adet | 2,500 | 5,000
Arka Aks Seti | 25mm Aks, Hub, Rulman | 1 set | 5,500 | 5,500
Jant ve Lastik | Karting Tipi | 4 set | 3,000 | 12,000
Fren Sistemi | Hidrolik Disk | 1 set | 4,000 | 4,000
Direksiyon Sistemi | Simit, Mil, Rot Kolları | 1 set | 3,500 | 3,500
Elektrik Bağlantı Elemanları | Kablo, Pabuç, Kontaktör, Buton | - | 3,000 | 3,000
Dış Hizmet Alımı | CNC Büküm İşçiliği | - | 3,500 | 3,500
Sarf Malzemeler | Kaynak, Civata, Boya | - | 3,000 | 3,000
Genel Toplam | | | | 97,420 TL

Öğrenci projesi olması nedeniyle işçilik maliyeti bütçeye yansıtılmamıştır. Ancak endüstriyel üretimde yaklaşık 120 saatlik mühendislik ve montaj işçiliği (tahmini 70.000 TL) maliyete eklenmelidir. İmalat yöntemi olarak boru büküm (CNC mandrel büküm) ve TIG kaynağı öngörülmüştür.

BÖLÜM 8. SONUÇ, TARTIŞMA VE ÖNERİLER

Bu çalışmada, "Yol Tutuş Odaklı Elektrikli Go-Kart Tasarımı" projesi kapsamında literatürde başarısı kanıtlanmış bir şasi geometrisi referans alınarak, elektrikli tahrik sistemine uygun, performanslı bir araç konsepti geliştirilmiştir. Projede "mühendislik hesaplamalarına dayalı tasarım" ilkesi, projenin her aşamasında temel alınmıştır. Elde edilen temel bulgular şunlardır:

1. Dinamik Performans: Yarı-Statik yük transferi yöntemiyle yapılan hesaplamalar, şasinin viraj dışı tekerleklerinde oluşan maksimum yükü ve iç tekerlekteki hafiflemeyi doğrulamıştır.
2. Yapısal Güvenlik: S355 çeliği kullanılarak yapılan FEA analizlerinde, en kritik senaryoda dahi maksimum gerilme 283 MPa seviyesinde kalmış, akma sınırının (355 MPa) altında olduğu doğrulanmıştır.
3. Yorulma Ömrü: Arka aks mili için yapılan Soderberg analizi, dinamik yükler altında milin sonsuz ömre sahip olacağını göstermiştir.
4. Enerji Verimliliği: 1.7 kW motor ve 1.5 kWh batarya paketi ile aracın teorik olarak 60 km/s hıza ulaşabileceği ve 20 dakikalık yarış seansını tamamlayabileceği doğrulanmıştır.

Kısıtlar ve Öneriler: Çalışma, tek kişilik bir proje olması ve bütçe kısıtları nedeniyle sanal prototipleme ile sınırlı kalmıştır. Ancak bu durum, detaylı analizlerin yapılmasına engel olmamış, aksine simülasyon araçlarının etkin kullanımını teşvik etmiştir. Ayrıca, batarya teknolojisindeki gelişmeler takip edilerek, daha hafif ve yüksek kapasiteli Li-Po (Lityum Polimer) hücrelerin kullanımı, aracın ağırlık/güç oranını daha da iyileştirebilir.

Sonuç olarak bu rapor, bir mühendislik öğrencisinin, kısıtlı imkanlarla dahi olsa, doğru metodoloji, derinlemesine literatür araştırması ve ileri mühendislik hesaplamaları ile endüstriyel standartlarda araç tasarımı ortaya koyabileceğini göstermektedir.

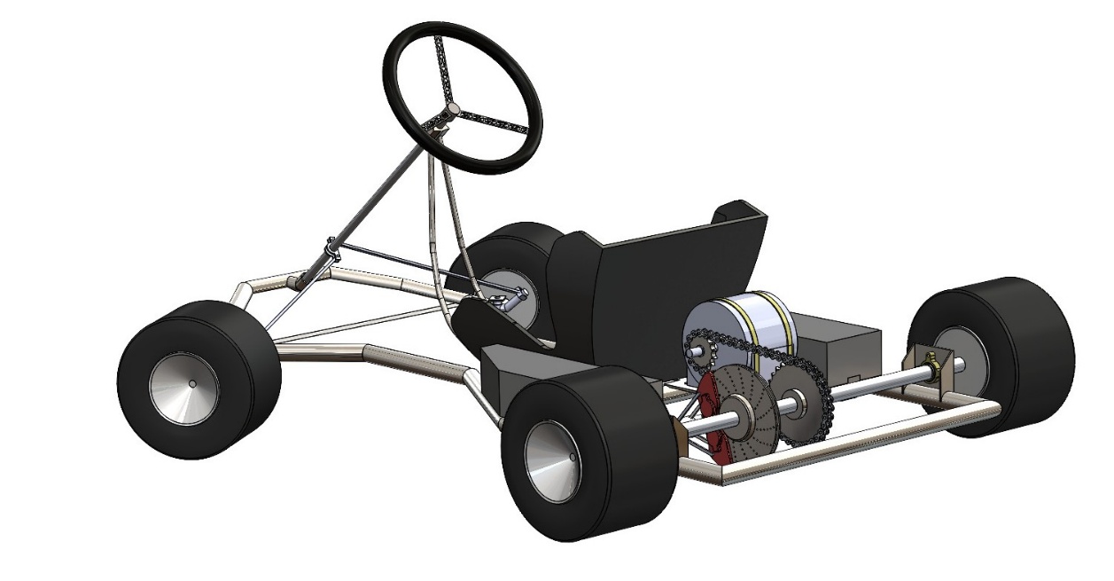
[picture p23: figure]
tekerlek, taşımak, nakletmek, araba lastiği, Araba parçası içeren bir resim Yapay zeka tarafından oluşturulmuş içerik yanlış olabilir.

Şekil 8.1. Tamamlanan elektrikli go-kart tasarımının güç aktarım ve arka aks bileşenlerini gösteren arka-izometrik görünümü.

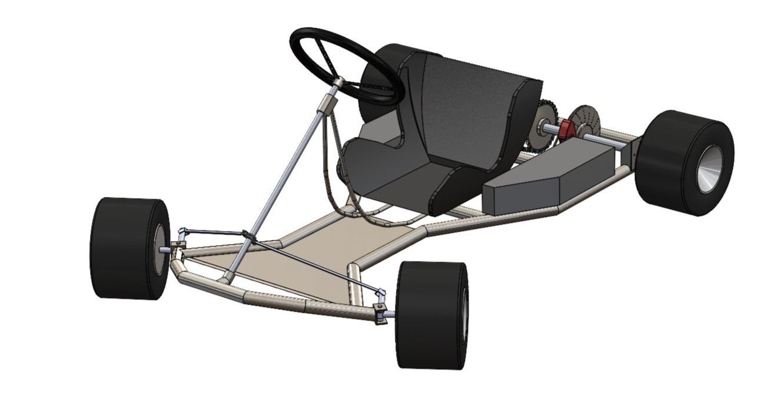
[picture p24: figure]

Şekil 8.2. Tasarımı tamamlanan aracın genel montaj görünümü ve direksiyon sistemi detayları.

KAYNAKLAR

Budynas, R.G. & Nisbett, K.J. (2011). Shigley’s Mechanical Engineering Design. 9th ed. New York, NY: McGraw-Hill.

Dassault Systèmes. (2023). SolidWorks Simulation Technical Reference. Vélizy-Villacoublay, France.

Ehsani, M., Gao, Y. & Emadi, A. (2010). Modern Electric, Hybrid Electric, and Fuel Cell Vehicles: Fundamentals, Theory, and Design. 2nd ed. Boca Raton, FL: CRC Press.

Gillespie, T.D. (1992). Fundamentals of Vehicle Dynamics. SAE International.

Jazar, R. (2014). Vehicle Dynamics: Theory and Application. 2nd ed. New York, NY: Springer.

Kır, E. (2024). Yol Tutuş Odaklı Go-Kart Tasarımı Ara Raporu. [Yayınlanmamış Rapor]. Sakarya Uygulamalı Bilimler Üniversitesi.

Larminie, J. & Lowry, J. (2012). Electric Vehicle Technology Explained. 2nd ed. London, UK: John Wiley & Sons.

Miao, Y., Hynan, P., von Jouanne, A. & Yokochi, A. (2019). 'Current Li-Ion Battery Technologies in Electric Vehicles and Opportunities for Advancements', Energies, 12(6), p. 1074.

Mihalić, T., Hoster, J., Tudić, V. & Kralj, T. (2023). 'Concept Design and Development of an Electric Go-Kart Chassis for Undergraduate Education in Vehicle Dynamics and Stress Applications', Applied Sciences, 13(20), p. 11312.

Milliken, W.F. & Milliken, D.L. (1995). Race Car Vehicle Dynamics. SAE International.

Sakarya Uygulamalı Bilimler Üniversitesi. (2022). Mühendislik Tasarımı ve Bitirme Çalışması Yönergesi. Sakarya.

Wong, J.Y. (2008). Theory of Ground Vehicles. 4th ed. Hoboken, NJ: John Wiley & Sons.

STANDART VE KISITLAR FORMU

1. Çalışmanın amacını özetleyiniz.

Bu çalışmanın amacı; içten yanmalı motorlu go-kart araçlarının çevresel dezavantajlarını ortadan kaldıran, elektrik motorunun yüksek tork avantajını kullanarak viraj performansı artırılmış bir elektrikli go-kart şasisinin tasarlanmasıdır. Temel odak noktası, süspansiyonu olmayan bu araçlarda şasi esnekliğini optimize ederek "jacking effect" (iç tekerleği kaldırma) mekanizmasını sağlamak ve aracın yol tutuşunu iyileştirmektir.

2. Çalışmanın tasarım boyutunu açıklayınız.

Bu çalışma, literatürde başarısı kanıtlanmış bir şasi geometrisinin (Mihalić ve ark., 2023) referans alınarak, yerel üretim imkanları ve güncel elektrikli araç bileşenlerine yeniden uyarlandığı ve optimize edildiği bir tasarım projesidir. Projenin genel geometrik konsepti literatüre dayanmakla birlikte; 3 boyutlu modelleme, malzeme ataması, sonlu elemanlar analizi ve güç aktarım sisteminin boyutlandırılması süreçleri tarafımdan gerçekleştirilmiştir. Tasarımın özgün katkısı, mevcut bir teorik modelin belirli kısıtlar altında doğrulanması ve detaylandırılması aşamalarını kapsamaktadır.

3. Bu çalışmada bir mühendislik problemini kendiniz formüle edip, çözdünüz mü?

Evet. Projedeki temel mühendislik problemi, ağır batarya paketlerinin şasiye eklenmesiyle bozulan ağırlık dağılımı ve şasi esnekliği sorunuydu. Formüle edilen problem; süspansiyonsuz bir araçta, diferansiyelsiz arka aksın viraj dönebilmesi için gerekli olan iç tekerlek yük transferinin sağlanması. Çözüm; şasi boru çapları ve et kalınlıkları optimize edilerek gerekli burulma rijitliği sağlanmış, "Yarı-Statik Yük Transferi" hesaplamaları ile viraj kuvvetleri teorik olarak bulunmuş ve Sonlu Elemanlar Analizi (FEA) ile şasinin bu yükler altındaki davranışı doğrulanmıştır.

4. Çalışmada kullandığınız yöntemler nelerdir ve önceki derslerde edindiğiniz hangi bilgi ve becerileri kullandınız?

Bu çalışmada Yarı-Statik Yük Analizi, Sonlu Elemanlar Analizi (FEA), Alt Modelleme (Sub-modeling) teknikleri ve Soderberg Yorulma Kriteri kullanılmıştır. Faydalanılan dersler:

- Fizik & Dinamik: Newton'un hareket yasaları, dairesel hareket ve merkezkaç kuvvetlerinin hesaplanarak viraj kuvvetlerinin formülize edilmesinde.
- Matematik II & Diferansiyel Denklemler: Analitik geometri bilgisi ile kinematik hesaplamaların (Ackermann geometrisi) türetilmesinde.
- Makine Dinamiği: Arka aks miline etkiyen dinamik yüklerin ve dişli-zincir mekanizmasındaki hız/tork dönüşümlerinin analiz edilmesinde.
- Elektrik Makinaları: BLDC motorların tork-hız karakteristiklerinin anlaşılması ve uygun motor seçiminin yapılmasında.
- Elektronik Devreler: Batarya konfigürasyonu ve Batarya Yönetim Sistemi (BMS) entegrasyonunun elektriksel güvenliğinin planlanmasında.
- Statik ve Mukavemet & Makine Elemanları: Şasi malzemesinin gerilme analizi, mil çapı hesabı ve yorulma ömrü değerlendirmesinde.

5. Kullandığınız veya dikkate aldığınız mühendislik standartları nelerdir?

- CIK-FIA (Uluslararası Karting Komisyonu) Standartları: Şasi iz genişliği ve aks aralığı gibi geometrik sınırlamalar için referans alınmıştır.
- TS EN 10210 / AISI Standartları: Şasi üretiminde kullanılan S355 (Yapı çeliği) malzeme standartları.
- SolidWorks Simulation Standartları: FEA analizlerinde kullanılan Von Mises akma kriterleri.

6. Kullandığınız veya dikkate aldığınız gerçekçi kısıtlar nelerdir?

a. Ekonomi: Profesyonel yarış şasilerinde kullanılan Krom-Molibden (4130) çeliği yerine, öğrenci bütçesine uygun ve kolay temin edilebilen S355 yapı çeliği tercih edilmiştir. Maliyet analizinde ithal parçalar döviz kuru riskine göre değerlendirilmiştir.
b. Çevre Sorunları: İçten yanmalı motorların egzoz emisyonları elimine edilerek "sıfır emisyon" hedeflenmiştir.
c. Sürdürülebilirlik: Fosil yakıt bağımlılığını azaltan elektrikli tahrik sistemi kullanılmıştır. Ayrıca arka aks tasarımında yorulma ömrü hesaplanarak parçanın uzun ömürlü olması hedeflenmiştir.
d. Üretilebilirlik: Karmaşık döküm parçalar yerine, boru büküm ve kaynak yöntemleri ile üretilebilecek bir geometri tasarlanmıştır. Montaj kolaylığı için standart rulman ve bağlantı elemanları seçilmiştir.
e. Etik: Bu çalışma süresince "Akademik Dürüstlük" ilkesine tam sadakat gösterilmiştir. Tasarımın temelini oluşturan referans çalışma ve kullanılan formüllerin kaynakları rapor içerisinde ve kaynakçada şeffaf bir şekilde belirtilmiştir. Varsayımlar net bir dille ifade edilerek yanıltıcı beyanlardan kaçınılmıştır.
f. Sağlık: Kapalı alan (indoor) pistlerdeki egzoz gazı soluma riski ortadan kaldırılmıştır. Sürücü güvenliği için batarya paketleri şasi yanlarına, sürücüden izole şekilde yerleştirilmiştir.
g. Güvenlik: Batarya sistemi için Aşırı Akım ve Sıcaklık korumalı BMS (Batarya Yönetim Sistemi) kullanılmıştır. Şasi analizlerinde dinamik yük faktörleri kullanılarak darbe anında mukavemet garanti altına alınmıştır.
h. Sosyal ve Politik Sorunlar: Otomotiv endüstrisindeki elektrifikasyon dönüşümüne paralel olarak, gürültü kirliliğini azaltan ve yenilenebilir enerjiye uyumlu bir araç konsepti sunulmuştur.

Proje Çalışmasının Birleşmiş Milletler Sürdürülebilir Kalkınma Amaçları (BM SKA) Bakımından İncelenmesi

7. Bu proje çalışmasının Birleşmiş Milletler tarafından belirlenen Sürdürülebilir Kalkınma Amaçları (SKA) ile ilişkisini değerlendiriniz.

a) Amaçları (SKA) ile ilişkisini değerlendiriniz.

- 7. Amaç: Erişilebilir ve Temiz Enerji
- 9. Amaç: Sanayi, Yenilikçi ve Altyapı
- 11. Amaç: Sürdürülebilir Şehirler ve Topluluklar
- 13. Amaç: İklim Eylemi

b) Belirlediğiniz SKA(lar) ile proje çıktıları arasındaki ilişkiyi kısaca açıklayınız.

Proje kapsamında tasarlanan elektrikli go-kart, fosil yakıtlı içten yanmalı motorların yerine yüksek verimli elektrikli tahrik sistemlerinin (BLDC motor ve Li-ion batarya) kullanılmasıyla 7. Amaç (Erişilebilir ve Temiz Enerji) hedefine doğrudan katkı sağlamaktadır. Egzoz emisyonlarının sıfırlanması, özellikle kapalı alan (indoor) pistlerde hava kalitesini artırarak ve karbon ayak izini düşürerek 13. Amaç (İklim Eylemi) ile paralellik göstermektedir.

Mühendislik açısından bakıldığında; şasi geometrisinin sanal ortamda Sonlu Elemanlar Analizi (FEA) ve Yarı-Statik Yük Transferi yöntemleriyle optimize edilmesi, malzeme tasarrufu sağlayan yenilikçi bir tasarım süreci ortaya koymaktadır. Geleneksel deneme-yanılma yöntemleri yerine simülasyon tabanlı bir AR-GE süreci yürütülmesi 9. Amaç (Sanayi, Yenilikçilik ve Altyapı) kapsamına girmektedir. Ayrıca gürültü ve çevre kirliliğinin azaltılması, şehir içi eğlence ve ulaşım araçlarının sürdürülebilirliğine örnek teşkil ederek 11. Amaç (Sürdürülebilir Şehirler ve Topluluklar) ile ilişkilidir.

BM Sürdürülebilir Kalkınma Amaçları

1. Yoksulluğa Son | 9. Sanayi, Yenilikçilik ve Altyapı
2. Açlığa Son | 10. Eşitsizliklerin Azaltılması
3. Sağlık ve Kaliteli Yaşam | 11. Sürdürülebilir Şehirler ve Topluluklar
4. Nitelikli Eğitim | 12. Sorumlu Üretim ve Tüketim
5. Toplumsal Cinsiyet Eşitliği | 13. İklim Eylemi
6. Temiz Su ve Sanitasyon | 14. Sudaki Yaşam
7. Erişilebilir ve Temiz Enerji | 15. Karasal Yaşam
8. İnsana Yakışır İş ve Ekonomik Büyüme | 16. Barış, Adalet ve Güçlü Kurumlar
| 17. Amaçlar İçin Ortaklıklar

Çalışmanın Adı | Yol Tutuş Odaklı Elektrikli Go-Kart Tasarımı ve Yapısal Optimizasyonu
Çalışmayı Hazırlayan | Erdoğan KIR
Danışman Onayı | Doç. Dr. Gökhan ATALI

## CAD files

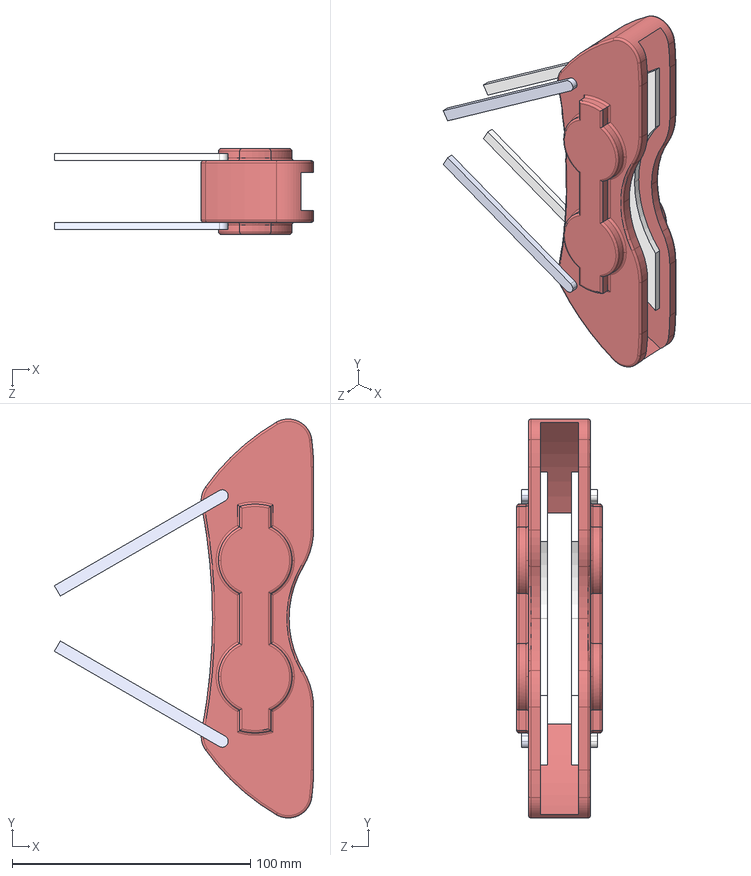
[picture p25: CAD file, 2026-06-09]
CAD_Models/STEP/frenkaliper.STEP
108.9 x 167.6 x 36.0 mm

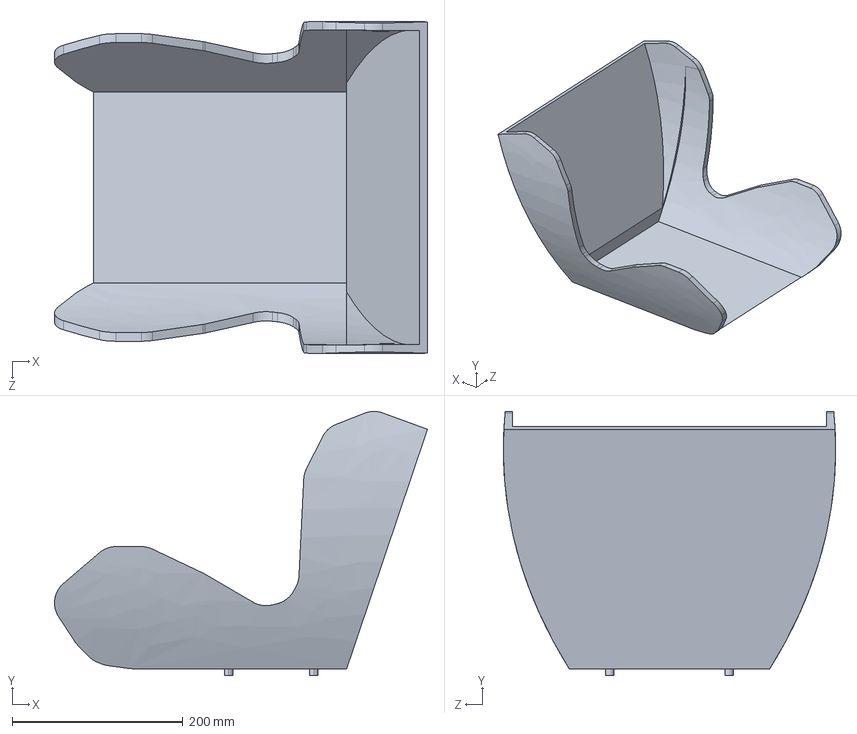
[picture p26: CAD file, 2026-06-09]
CAD_Models/STEP/koltuk.STEP
437.5 x 309.9 x 389.8 mm

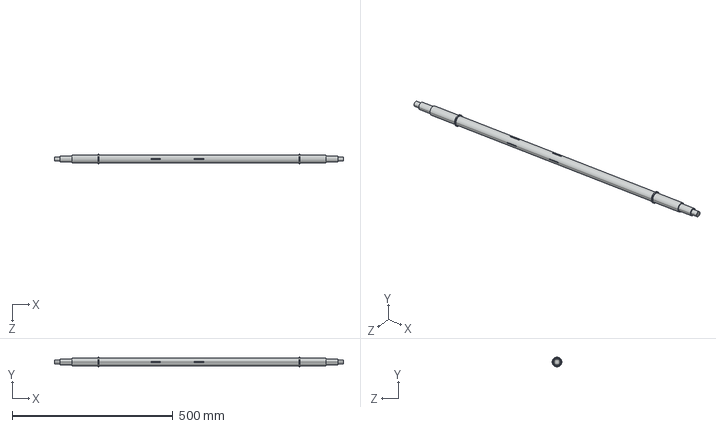
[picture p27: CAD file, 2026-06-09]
CAD_Models/STEP/arkamil.STEP
900.0 x 30.0 x 30.0 mm

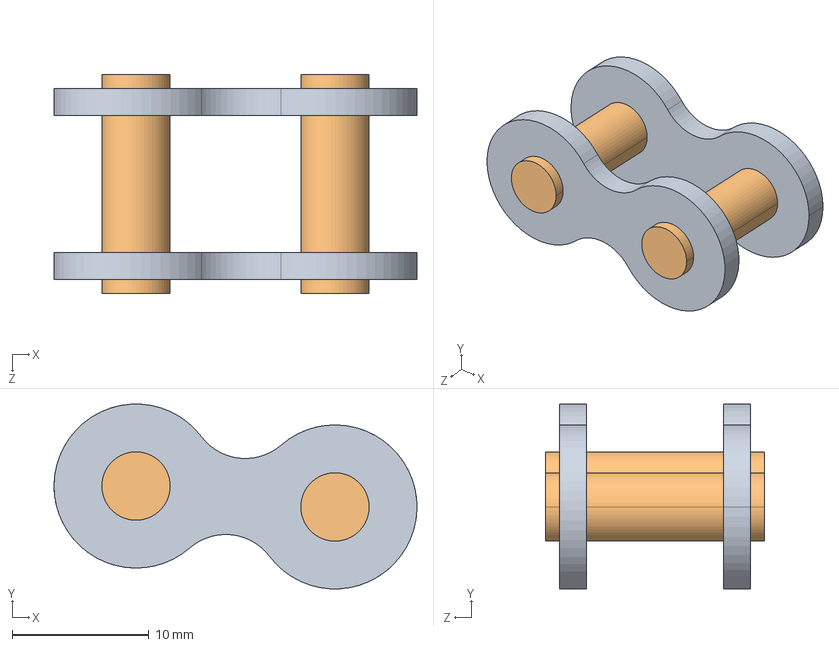
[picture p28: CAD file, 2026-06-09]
CAD_Models/STEP/zincir-dis.STEP
26.6 x 13.5 x 16.0 mm

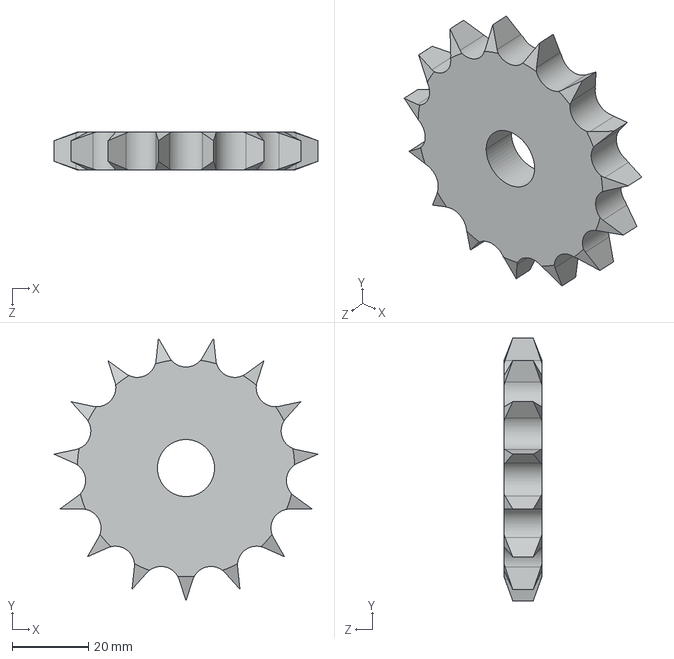
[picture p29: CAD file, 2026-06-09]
CAD_Models/STEP/arkadisli2.STEP
69.4 x 69.0 x 10.0 mm

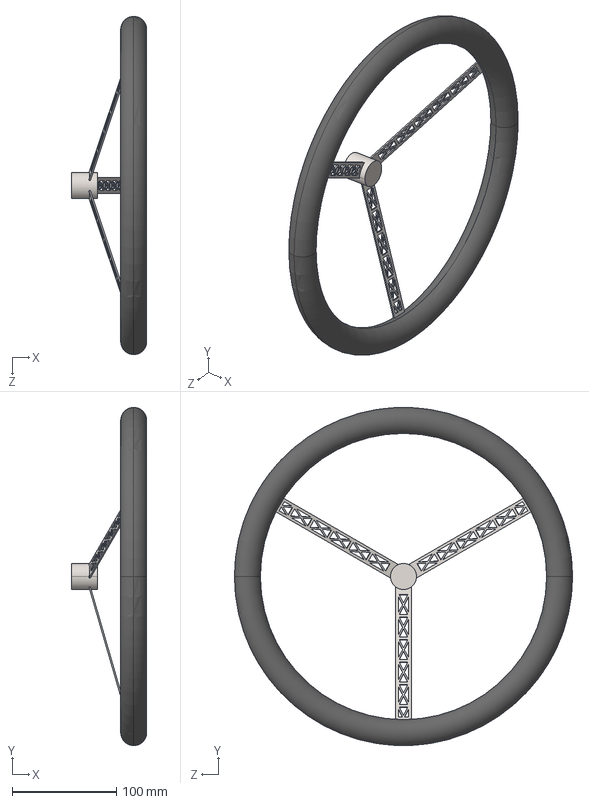
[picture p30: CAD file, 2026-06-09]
CAD_Models/STEP/direksiyon.STEP
72.5 x 324.8 x 325.0 mm

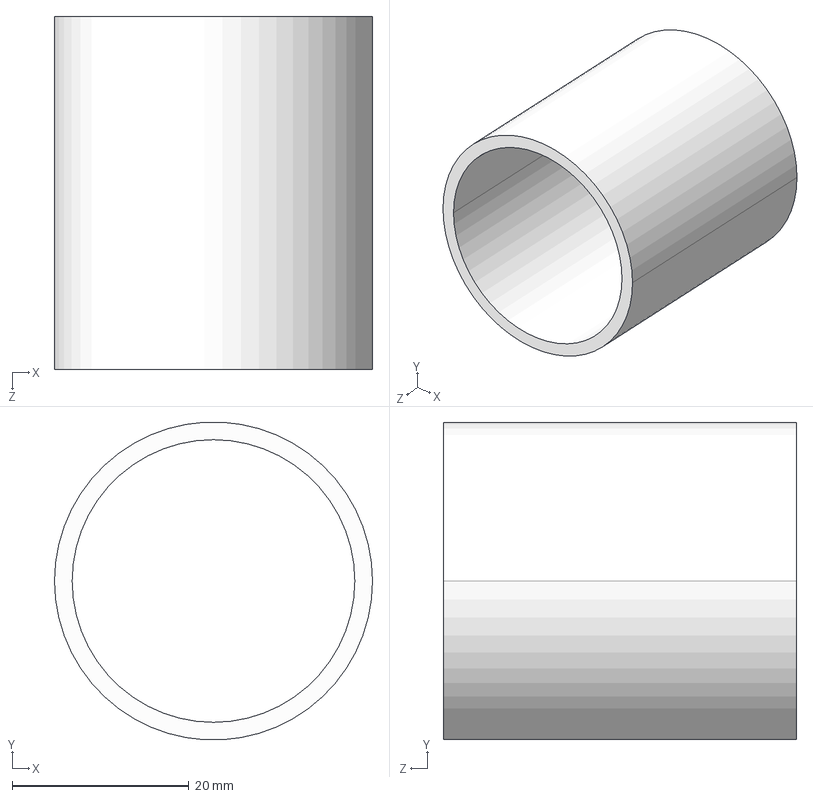
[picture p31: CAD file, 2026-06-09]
CAD_Models/STEP/halka.STEP
36.0 x 35.9 x 40.0 mm

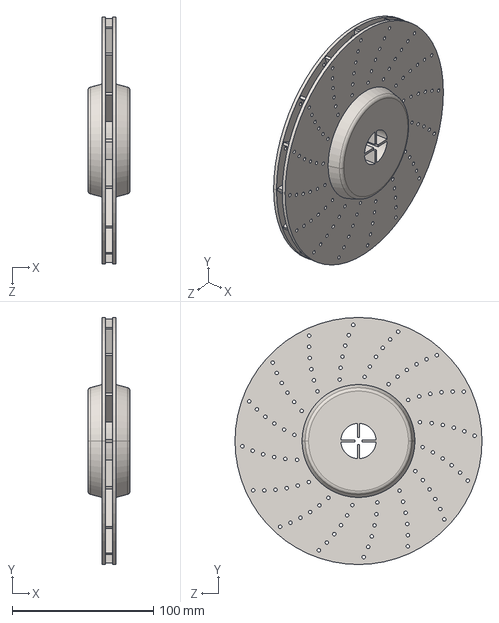
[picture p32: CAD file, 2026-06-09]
CAD_Models/STEP/frendisk.STEP
30.0 x 175.0 x 175.0 mm

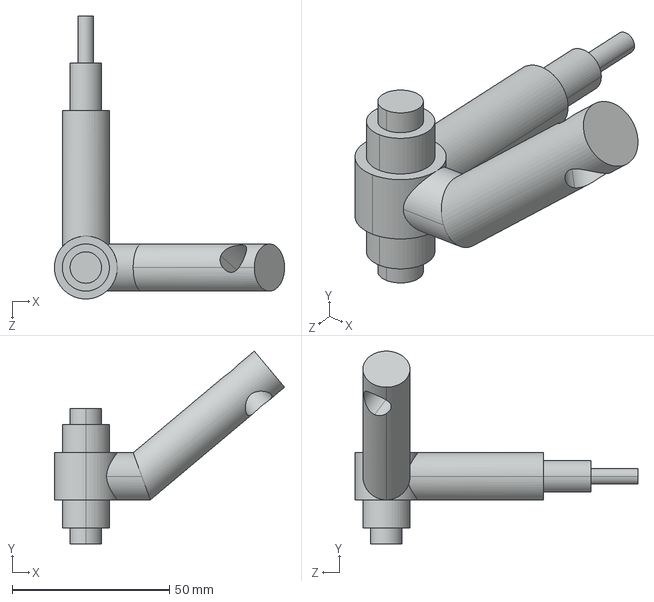
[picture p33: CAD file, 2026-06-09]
CAD_Models/STEP/önjantbaglanti-sag.STEP
73.2 x 61.3 x 90.0 mm

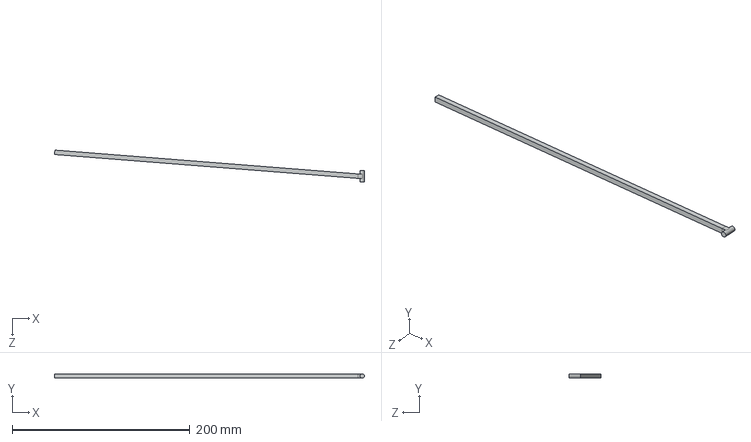
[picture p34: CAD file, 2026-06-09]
CAD_Models/STEP/direksiyonbaglanti1-sag.STEP
349.1 x 5.00 x 35.9 mm

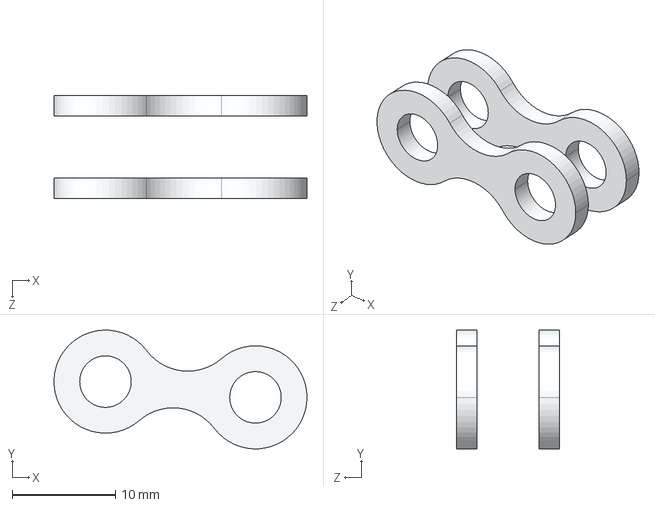
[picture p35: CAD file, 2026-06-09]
CAD_Models/STEP/zincir-ic.STEP
24.5 x 11.5 x 10.0 mm

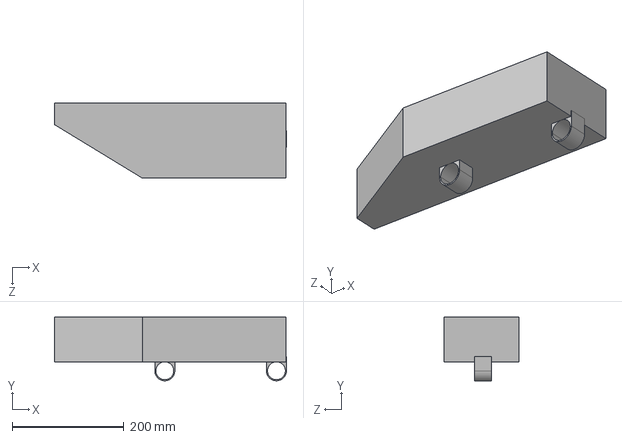
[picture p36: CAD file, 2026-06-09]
CAD_Models/STEP/batarya-sol.STEP
415.6 x 114.0 x 135.0 mm

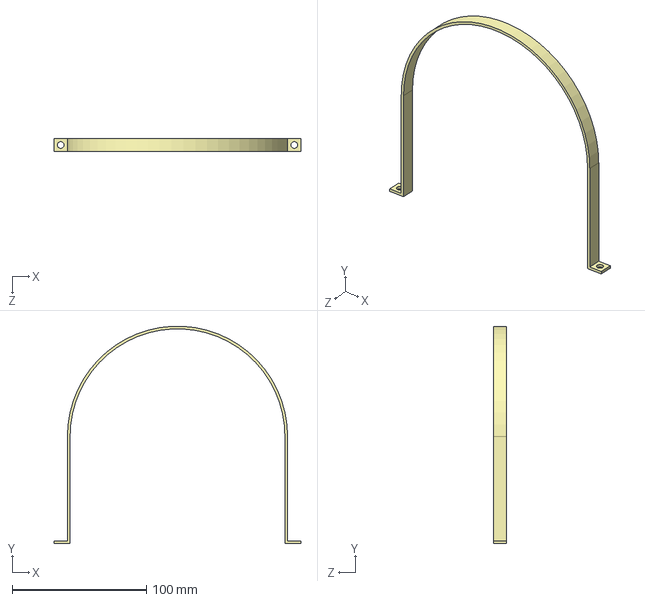
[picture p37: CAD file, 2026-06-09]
CAD_Models/STEP/motorbaglantibraket.STEP
184.0 x 161.9 x 10.0 mm

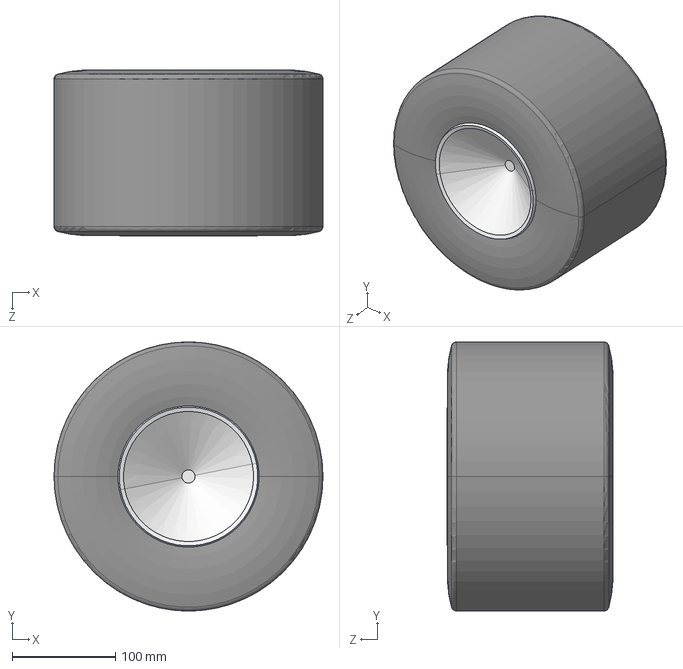
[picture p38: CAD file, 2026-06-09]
CAD_Models/STEP/jantlastikbirlesik.STEP
260.0 x 260.0 x 160.1 mm

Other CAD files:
CAD_Models/STEP/batarya-sag.STEP
CAD_Models/STEP/önjantbaglanti.STEP
CAD_Models/SLDPRT/arkadisli.SLDPRT
CAD_Models/SLDPRT/arkadisli2.SLDPRT
CAD_Models/SLDPRT/arkamil.SLDPRT
CAD_Models/SLDPRT/arkarulman.SLDPRT
CAD_Models/SLDPRT/batarya-sag.SLDPRT
CAD_Models/SLDPRT/batarya-sol.SLDPRT
CAD_Models/SLDPRT/direksiyon.SLDPRT
CAD_Models/SLDPRT/direksiyonbaglanti1-sag.SLDPRT
CAD_Models/SLDPRT/direksiyonbaglanti1.SLDPRT
CAD_Models/SLDPRT/direksiyonbaglanti2.SLDPRT
CAD_Models/SLDPRT/direksiyonmil.SLDPRT
CAD_Models/SLDPRT/frendisk.SLDPRT
CAD_Models/SLDPRT/frenkaliper.SLDPRT
CAD_Models/SLDPRT/halka.SLDPRT
CAD_Models/SLDPRT/jantlastikbirlesik.SLDPRT
CAD_Models/SLDPRT/koltuk.SLDPRT
CAD_Models/SLDPRT/motor.SLDPRT
CAD_Models/SLDPRT/motorbaglantibraket.SLDPRT
CAD_Models/SLDPRT/sasi.SLDPRT
CAD_Models/SLDPRT/zincir-dis.SLDPRT
CAD_Models/SLDPRT/zincir-ic.SLDPRT
CAD_Models/SLDPRT/önjantbaglanti-sag.SLDPRT
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

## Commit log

2026-06-09 Initial commit: Added CAD files, FEA results, images and project report
    [arkadisli.SLDPRT, arkadisli.STEP, arkadisli2.SLDPRT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]
2026-06-09 Finalized CAD models
